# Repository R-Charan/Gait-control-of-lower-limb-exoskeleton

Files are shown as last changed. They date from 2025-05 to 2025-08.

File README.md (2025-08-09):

# Lower Limb Exoskeleton with Gait Control System

## 🦾 Project Overview

This project presents the design and development of an **underactuated lower limb exoskeleton** capable of augmenting human strength by **400%** while maintaining natural gait patterns. Unlike traditional 6+ DOF systems, our innovative 4-DOF approach (hip and knee joints only) provides effective power augmentation at reduced complexity and cost.

### Key Achievements
- **400% strength augmentation** validated through EMG testing
- **5x peak strength amplification** capability
- **Real-time gait pattern tracking** and control
- **Novel underactuated approach** with multi-point ground contact
- **Custom control architecture** with motion disturbance rejection

---

## Project Objectives

1. **Motor Control**: Configure torque and position controllers for BLDC motors
2. **Gait Analysis**: Analyze differences in gait patterns with/without load and exoskeleton
3. **Controller Development**: Implement PD + Bang-Bang controller for desired gait pattern tracing
4. **Strength Validation**: Test controller efficacy in augmenting user strength through force analysis
5. **EMG Validation**: Quantify strength amplification using electromyography data

---

## Technical Architecture

### Hardware Components
- **Motors**: BLDC motors with torque/position control
- **Sensors**: Inertial Measurement Unit (IMU) for feedback
- **Control**: Custom microcontroller unit with motor drivers
- **Power**: Battery system for portable operation
- **Mechanical**: 4-DOF exoskeleton frame (hip and knee joints)

### Control System
```
Setpoint Generation → PD Controller → Bang-Bang Control → Motor Actuation
        ↑                                                        ↓
    Gait Pattern                                            IMU Feedback
```

### Software Architecture
- **Angle Update Module**: Real-time joint angle monitoring
- **Controller Module**: PD control with dynamic motion disturbance rejection
- **Actuation Module**: Speed-to-duty cycle mapping with threshold-based system control

---

##  Methodology

### 1. Hardware Setup & Integration
- Motor and driver configuration
- IMU calibration and mounting
- Battery and power management system
- Mechanical assembly and testing

### 2. Control Algorithm Development
- **Position Controller**: Single DOF motor position control
- **Gait Generation**: Algorithm for natural walking pattern synthesis
- **PD + Bang-Bang Controller**: Hybrid approach for robust tracking
- **Motion Compensation**: Dynamic disturbance rejection system

### 3. Validation & Testing
- **Single leg gait cycle testing**
- **Controller response analysis**
- **EMG data acquisition and analysis**
- **Strength augmentation quantification**

---

## Results

### Control Performance
- Successfully achieved repeating gait cycles
- Stable position control with measured time-domain response
- Effective motion disturbance rejection

### Strength Augmentation Validation
**EMG Analysis Results:**
- **Without Support**: Max amplitude ~0.8mV (burst activity)
- **With Exoskeleton**: Max amplitude ~4mV with continuous 1mV baseline
- **Conclusion**: 5x peak strength amplification, 400% overall augmentation

### Key Findings
1. **Multi-core Processing**: Parallel control for multiple DOF systems recommended
2. **Speed vs. Torque Control**: Current-based control approaches preferred for robustness
3. **Impedance Control**: Direct torque input more effective than speed-based control
4. **Validation Success**: Low-cost prototype successfully augments user strength

---

## System Architecture

### Kinematic Model
```
Hip Joint (θh, ωh) → Thigh Link (lt) → Knee Joint (θk, ωk) → Shank Link (ls) → Ankle
```

### Compensation Algorithm
For undisturbed shank angular position during thigh motion:
```
θ̇k = -ωh (compensation velocity for knee actuator)
```

### Control Equations
- **Position Control**: PD controller with setpoint lookup table
- **Motion Compensation**: Dynamic adjustment based on hip joint velocity
- **Actuation Mapping**: Speed-to-duty cycle conversion with threshold control

---

## Implementation Details

### PCB Design
- Custom circuit board for motor control integration
- IMU interface and data acquisition
- Power management and battery monitoring

---

### Key Functions
- **Angle Update**: Real-time joint angle monitoring via IMU
- **Setpoint Lookup**: Gait pattern reference generation
- **Error Calculation**: Position error computation for control
- **Speed Mapping**: Controller output to motor speed conversion
- **Threshold Control**: Safety and performance optimization

---

## Performance Metrics

| Metric | Value | Validation Method |
|---|---|---|
| Strength Augmentation | 400% | EMG Analysis |
| Peak Strength Amplification | 5x | EMG Peak Comparison |
| Control DOF | 4 (Hip + Knee) | System Design |
| Response Time | Real-time | Controller Testing |
| Ground Contact | Multi-point | Mechanical Design |

---

## Future Work

### Immediate Improvements
- **Multi-core Implementation**: Parallel processing for enhanced performance
- **Torque-based Control**: Direct current control for improved robustness
- **Impedance Control**: Enhanced human-robot interaction
- **Response Tuning**: Further PD parameter optimization

### Advanced Features
- **Adaptive Control**: Machine learning-based gait adaptation
- **Wireless Communication**: Remote monitoring and control
- **Energy Harvesting**: Self-sustaining power systems
- **Full-body Integration**: Extension to upper limb assistance

---

## Team

**Project Members:**
- Adithya Venkata Narayanan – 111120001
- R Charan Bhardhwaj – 111120109

**Project Guides:**
- Dr. N Siva Shanmugam (Internal Guide)
- Dr. D Ezhilarasi (Co-Guide)

---

## Key References

1. **Kinoshita, H. (1985)**. Effects of different loads and carrying systems on selected biomechanical parameters describing walking gait. *Ergonomics, 28(9), 1347–1362.*

2. **Al-Shuka, et al. (2019)**. Biomechanics, actuation, and multi-level control strategies of power-augmentation lower extremity exoskeletons: an overview. *International Journal of Dynamics and Control, 7(4), 1462–1488.*

3. **Grimmer, et al. (2020)**. Human Lower Limb Joint Biomechanics in Daily Life Activities: A Literature Based Requirement Analysis for Anthropomorphic Robot Design. *Frontiers in Robotics and AI, 7.*

---

## Project Impact

This research addresses a critical gap in exoskeleton technology by demonstrating that **underactuated systems** can provide effective power augmentation comparable to traditional higher-DOF systems. The work contributes to:

- **Cost-effective Design**: Reduced complexity while maintaining performance
- **Novel Control Approach**: PD + Bang-Bang hybrid controller
- **Validated Performance**: Quantified strength augmentation through EMG
- **Real-world Application**: Practical solution for load-bearing augmentation

---

## License

This project is part of academic research conducted at National Institute of Technology, Tiruchirapalli. Please cite appropriately if using this work for research purposes.

*This project represents a significant step forward in making exoskeleton technology more accessible and practical for real-world applications.*

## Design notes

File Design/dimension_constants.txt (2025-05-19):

"thigh_width"= 3cm

"thigh_thickeness"= 1cm

"shin_thickness"= 0.6cm

"shin_width"= 5cm

"D1@Sketch7"="thigh_width"+2cm

"link_length" = 8.5cm

"D2@Sketch7"="link_length"

"D1@Boss-Extrude5"="thigh_thickeness"

"D2@Sketch8"="thigh_width"-2mm

"bolt head"= 4.2mm'With clearance

"D3@Sketch16"="bolt head"

"D4@Sketch16"="bolt head"

"D5@Sketch16"="bolt head"

"D6@Sketch16"="bolt head"

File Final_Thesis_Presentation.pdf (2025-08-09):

# Gait Control of Lower Body Exoskeleton

## B. Tech Final Year Project Review

Project Members

Adithya Venkata Narayanan – 111120001 R Charan Bhardhwaj – 111120109

Project Guides

Dr. N Siva Shanmugam (Internal Guide) Dr. D Ezhilarasi (Co – Guide)

# Introduction

What is Gait?
Gait refers to the movement pattern of the limbs during locomotion, commonly associated with walking. It involves a coordinated sequence of movements of the legs and arms to propel the body forward.
What happens to gait under load?
Adding weights alters the biomechanics of gait by increasing the load on muscles and joints. It may lead to changes in stride length, step frequency, and overall stability as the body adapts to the added load.

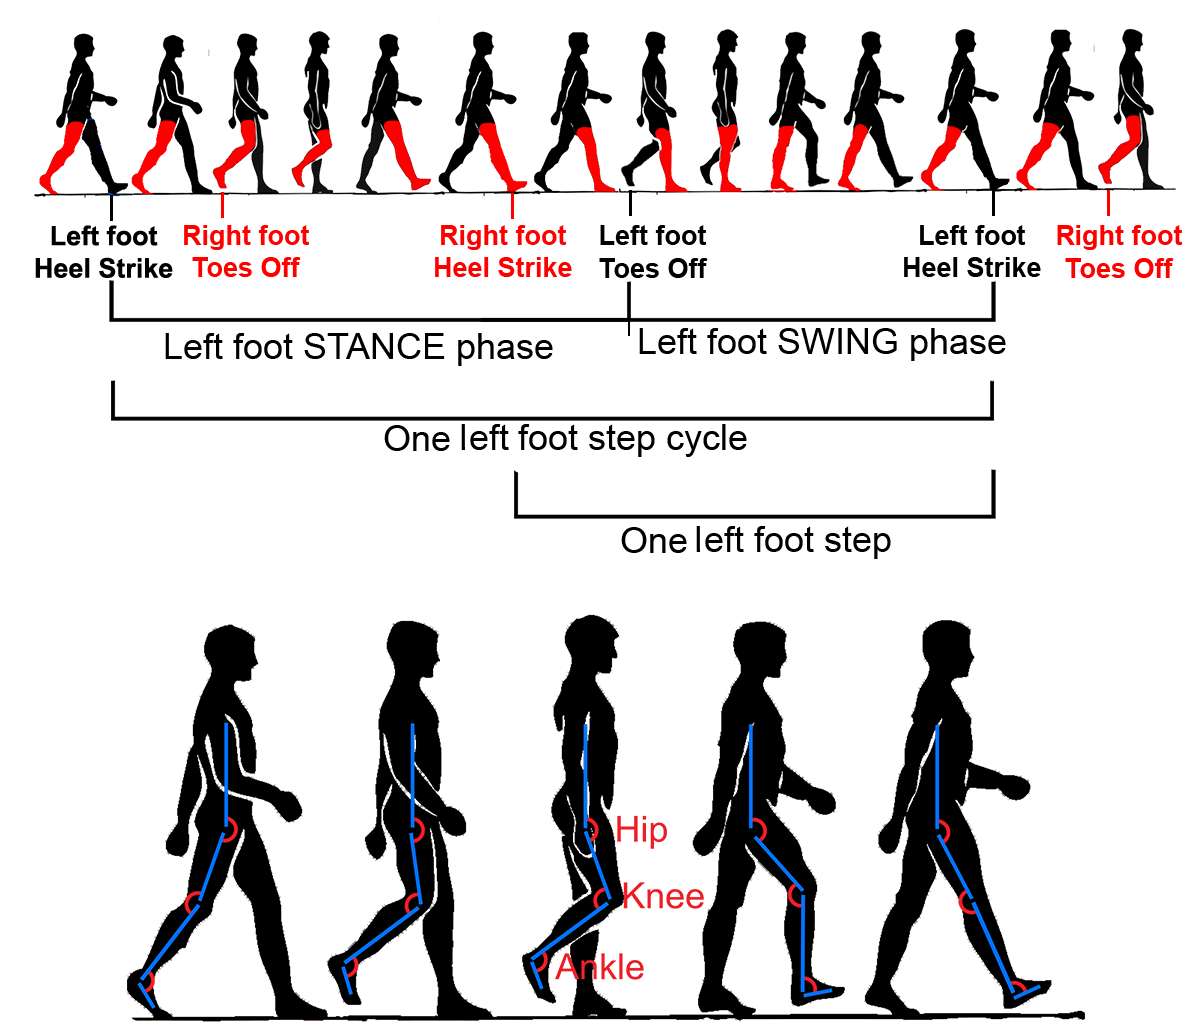
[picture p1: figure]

Image Source: Georgiou, T., et.al (2020)

# Introduction (Continued)

What are Exoskeletons?
Exoskeletons are wearable robotic devices (over specific regions or overall, of the body) designed to enhance physical performance. They augment power by providing mechanical assistance to muscles, reducing fatigue, and increasing endurance.
How do exoskeletons help?
Exoskeletons distribute weight more evenly across the body, changing the load path and thus reducing the strain on muscles and joints during weight-bearing activities. By supporting the load, exoskeletons enable individuals to carry heavier objects with less effort, improving overall mobility and productivity.

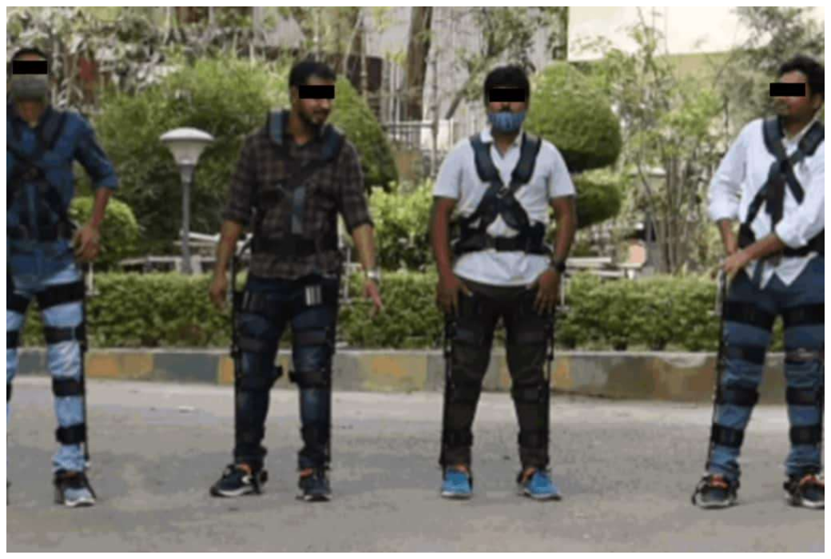
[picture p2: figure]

Image Source: DRDO developing exoskeleton for the Indian soldiers posted in high altitudes, Financial Express

# Literature Review

S.No | Source | Title | Inference
1 | Kinoshita, H. (1985). Ergonomics, 28(9), 1347–1362. | Effects of different loads and carrying systems on selected biomechanical parameters describing walking gait | Significant change of body posture and gait pattern observed when lifting heavy weights , indicating that the risk of encountering stress-related injuries is considerably greater as the load increased in magnitude.
2 | Al-Shuka, et. al (2019).International Journal of Dynamics and Control, 7(4), 1462– 1488. | Biomechanics, actuation, and multi-level control strategies of power-augmentation lower extremity exoskeletons: an overview | Factors such as interaction force wrench for control purpose, among others required for force augmentation to be considered for design of a control strategy for power augmentation in exoskeletons were discussed.
3 | Grimmer, et. al. (2020). Frontiers in Robotics and AI, 7. | Human Lower Limb Joint Biomechanics in Daily Life Activities: A Literature Based Requirement Analysis for Anthropomorphic Robot Design. | A study of the range of motion and joint parameters (velocity, acceleration, torque, and power)exhibited by healthy subjects alongside a motion study of actions (such as walking, jogging, running, climbing, and sitting to standing) was presented.

# Literature Review

S.No | Source | Title | Inference
4 | Zoss, A, et. al. (2006). IEEE-ASME Transactions on Mechatronics, 11(2), 128–138. | Biomechanical Design of the Berkeley Lower Extremity Exoskeleton (BLEEX) | Introduces the 14 DOF (7 DOF per leg) lower extremity exoskeleton for power augmentation that anthropomorphic in design.
5 | Amiri, M. S, et. al. (2019). IEEE Access, 7, 167210–167220. | Initialized Model Reference Adaptive Control for Lower Limb Exoskeleton | A comparative study of IMRAC and non-IMRAC rule on a closed-loop PID controller detailing the mathematical expression of the control schemes' LLE structure, transfer function, and convergence rates

# Literature Gap

- Augmentative exoskeletons are not available in the market, and the research sector covers

### the entire leg with hip, knee, and ankle actuators (at least 6 DOF). The under-actuated

exoskeletons (4 DOF, hip, and knee) in literature are still in the research phase, with their

### dynamic models either being treated as ones with single-point contact at the foot between the unit and the ground or having no contact with the ground (model, ends at above the

ankle joint). • A gap exists in the literature where the exoskeleton is underactuated, having a complete

metallic sole unit in contact with the ground (multi-point contact). • The approach for designing controller for exoskeletons and its implementation is not

available in literature.

# Aim

### - Our work involves designing a controller for an underactuated Lower Limb Exoskeleton (4 DOF, only hip and knee joint control) that enhances the user's load-bearing capacity and

testing the unit's efficacy on a flat plane. Thus, the feasibility of an underactuated system to provide power augmentation like traditional higher DOF exoskeletal systems is determined. • We aim to work on an approach that strikes a balance between extensive modelling and

### model free PID approaches. Studying kinematics and dynamics to design compensators for

over/undershoots on top of a PID architecture.

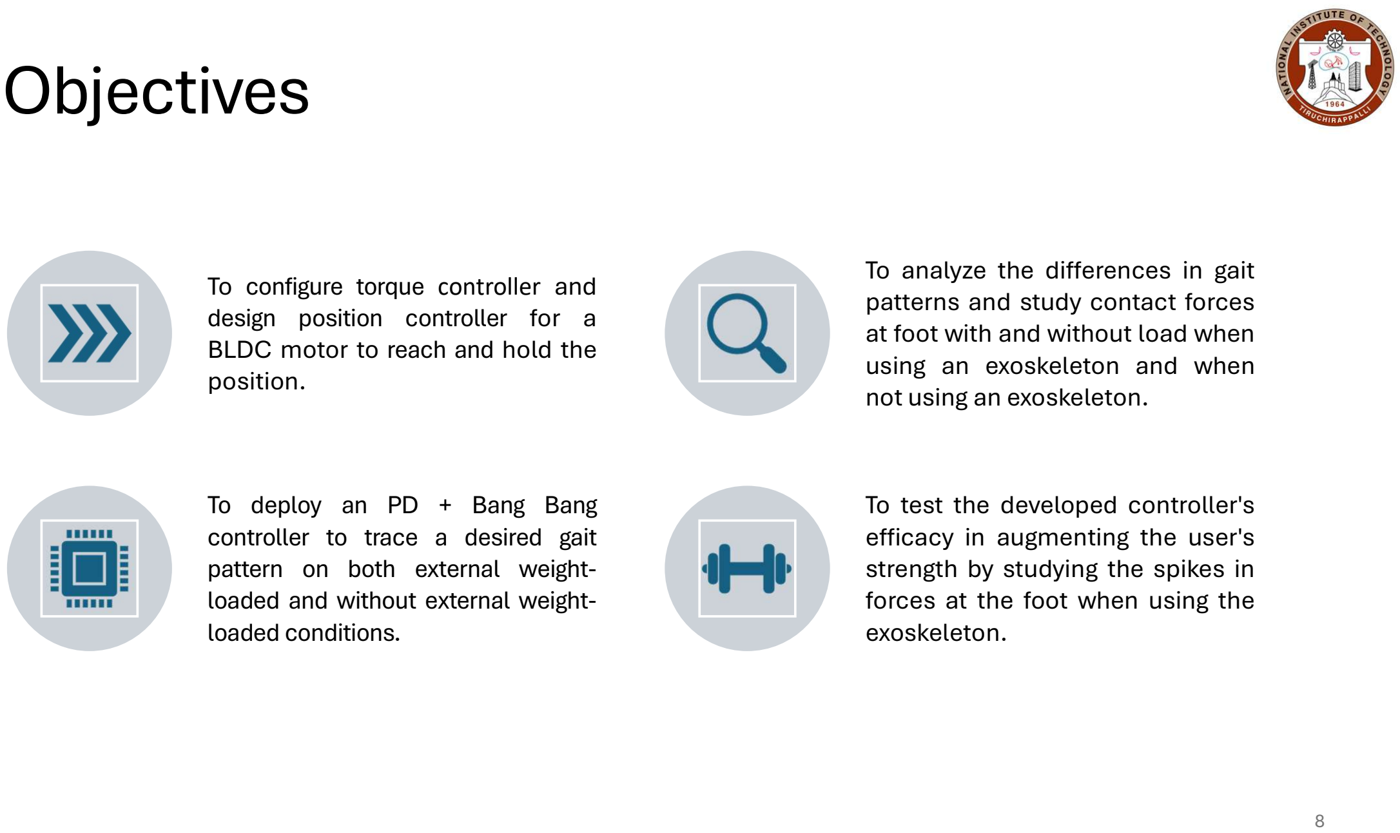
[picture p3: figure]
To configure torque controller and design position controller for a BLDC motor to reach and hold the position.; To analyze the differences in gait patterns and study contact forces at foot with and without load when using an exoskeleton and when not using an exoskeleton.; To deploy an PD + Bang Bang controller to trace a desired gait pattern on both external weight- loaded and without external weight- loaded conditions.; To test the developed controller's efficacy in augmenting the user's strength by studying the spikes in forces at the foot when using the exoskeleton.; Objectives

# Methodology

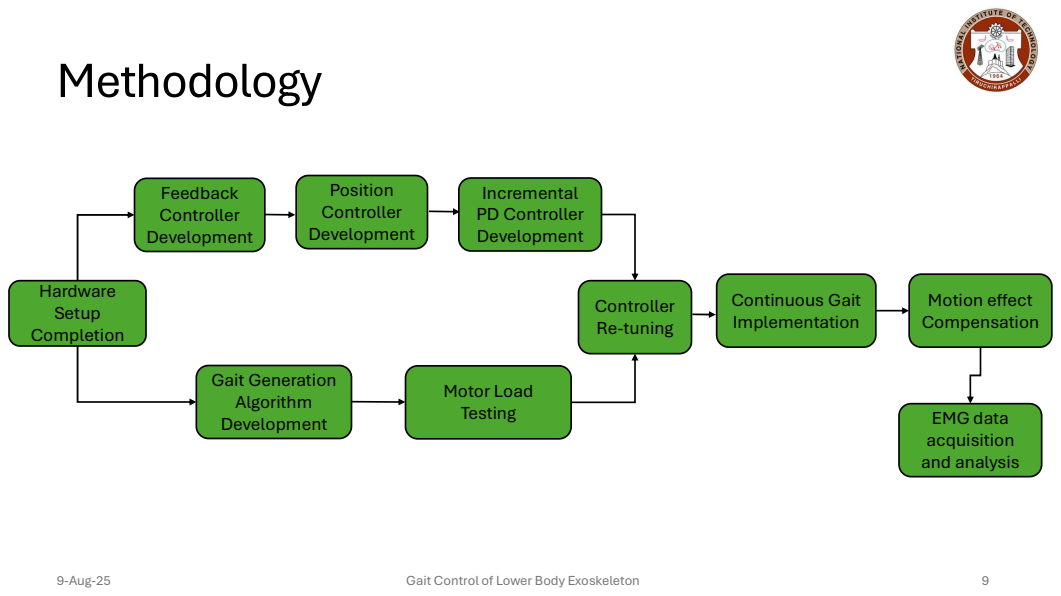
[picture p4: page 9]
9-Aug-25; Gait Control of Lower Body Exoskeleton; Hardware Setup Completion; Gait Generation Algorithm Development; Motor Load Testing; Position Controller Development; Incremental PD Controller Development; Controller Re-tuning; Continuous Gait Implementation; Motion effect Compensation; Feedback Controller Development; EMG data acquisition and analysis

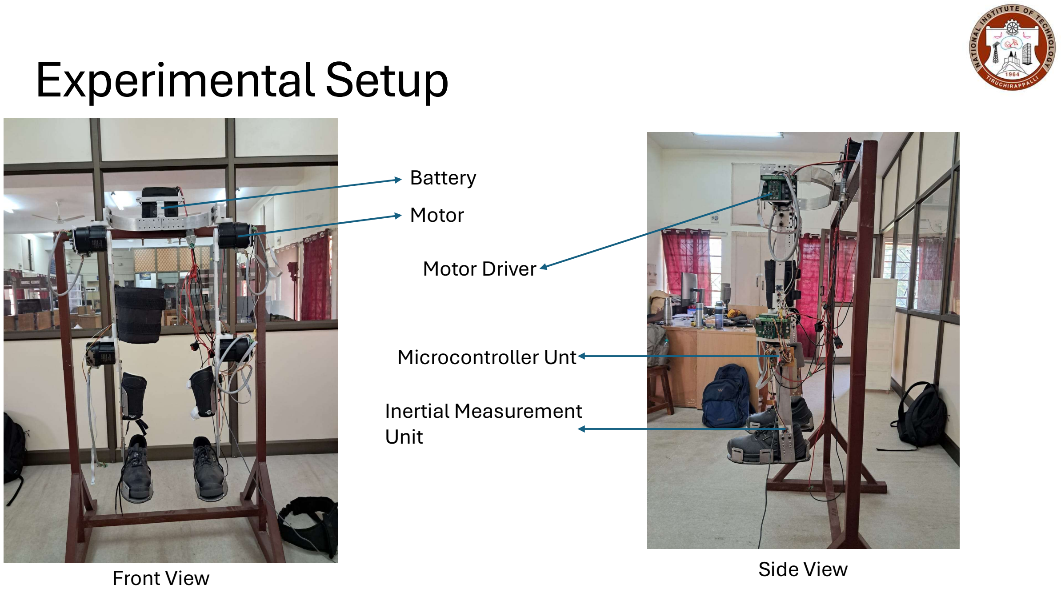
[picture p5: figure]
Experimental Setup; Motor; Battery; Front View; Motor Driver; Microcontroller Unt; Inertial Measurement Unit; Side View

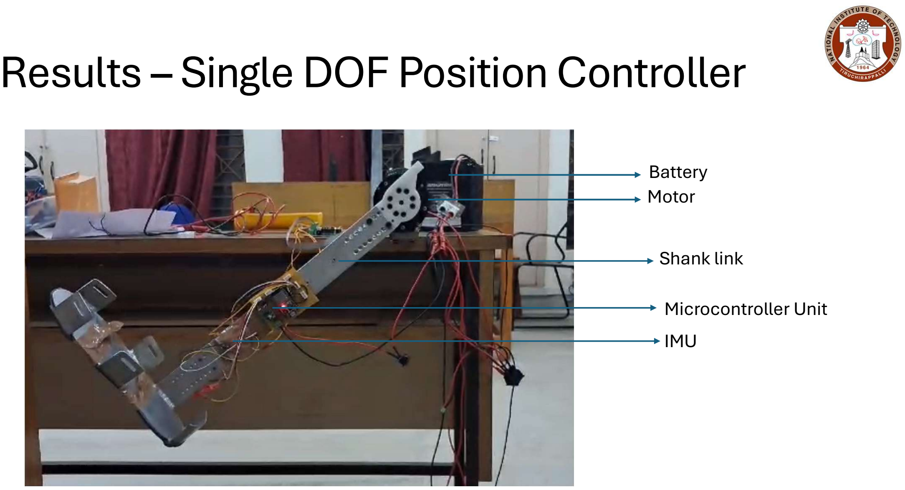
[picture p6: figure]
Battery Motor; Shank link; Microcontroller Unit IMU

# Results – Single DOF Position Controller

# Results – Gait Data Study and Visualization

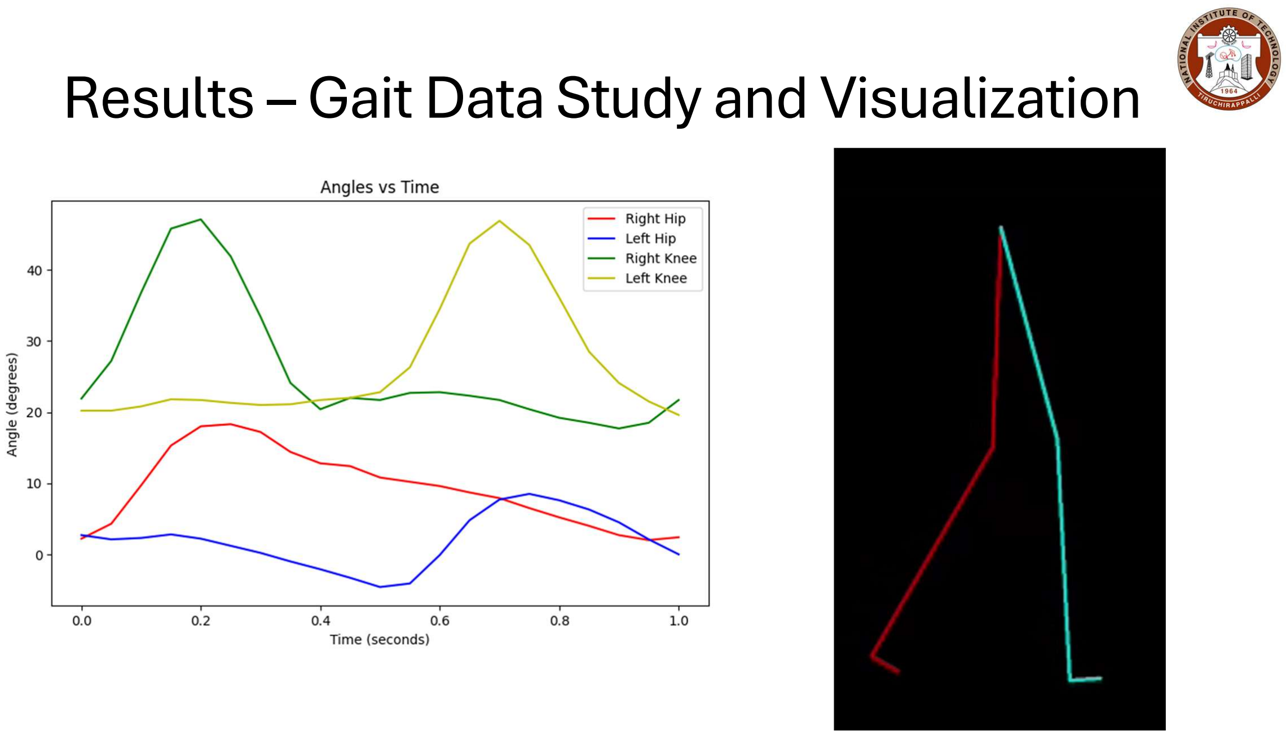
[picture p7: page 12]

# Controller Architecture

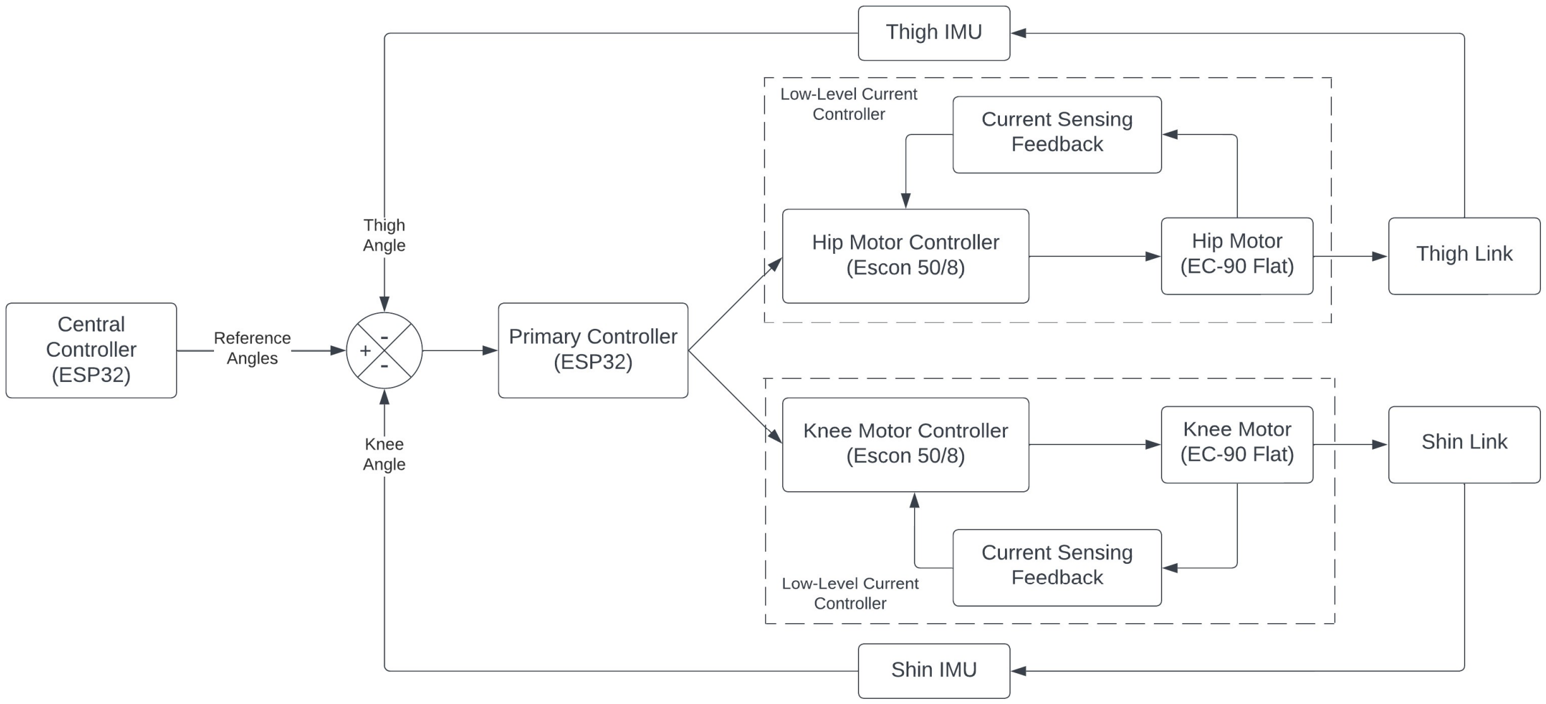
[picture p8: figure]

# Results - Single Leg Gait Cycle

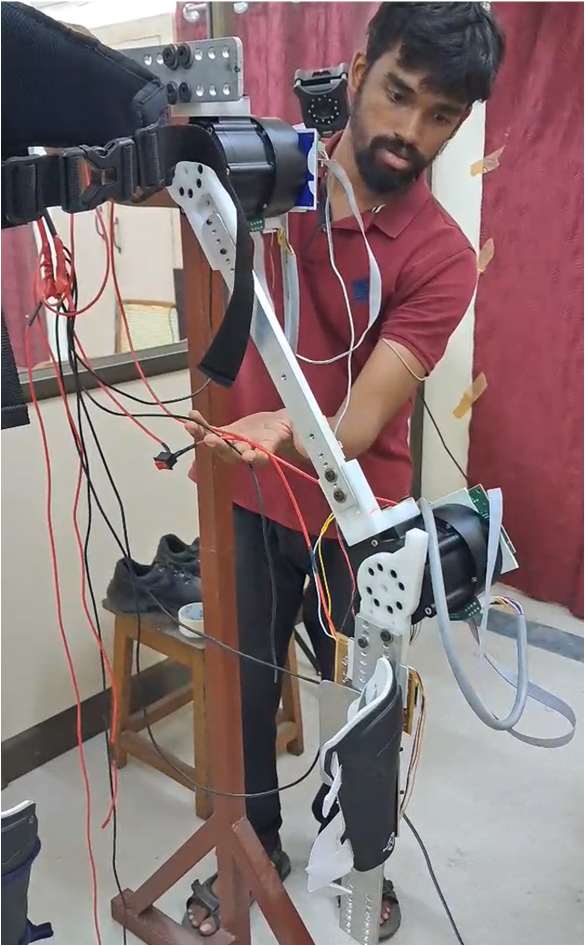
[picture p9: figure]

# Results – Controller Response

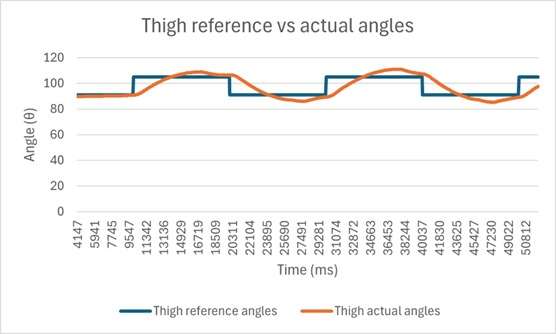
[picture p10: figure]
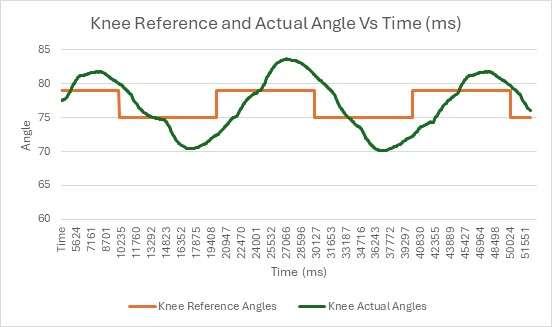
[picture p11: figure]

# Controller Response

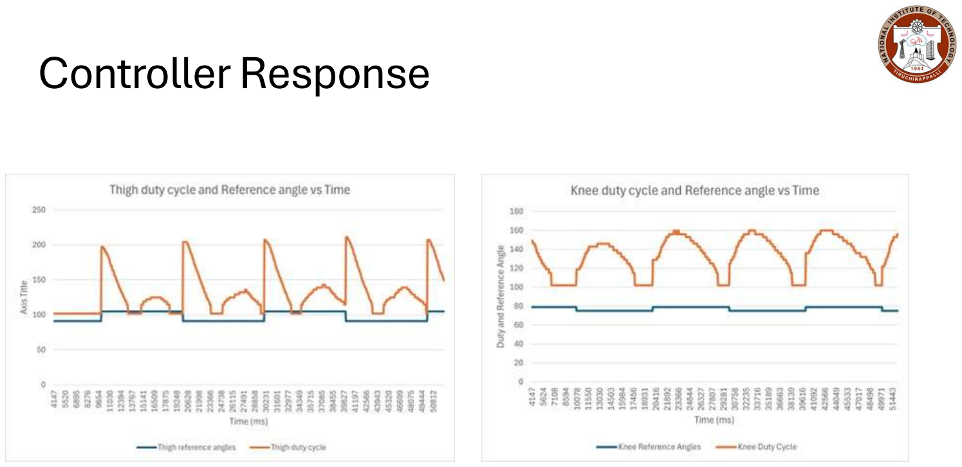
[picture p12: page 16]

# PCB Design

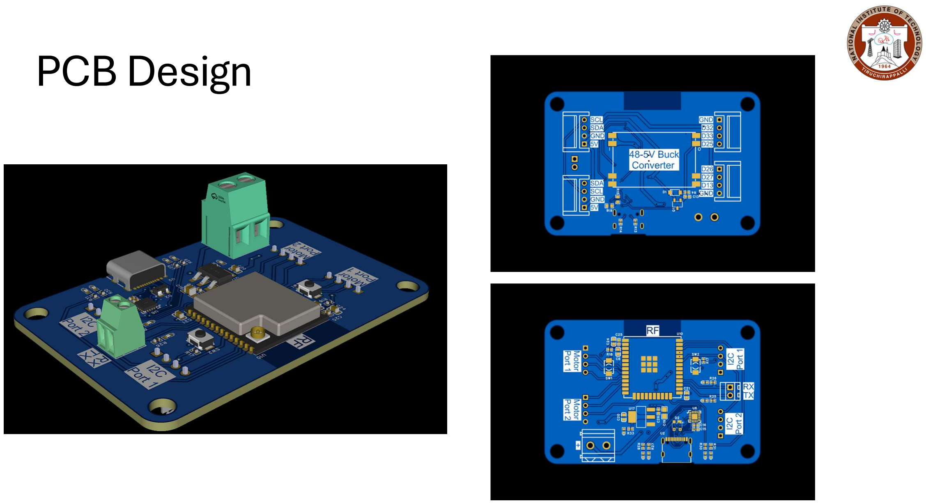
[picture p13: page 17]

# Code Base

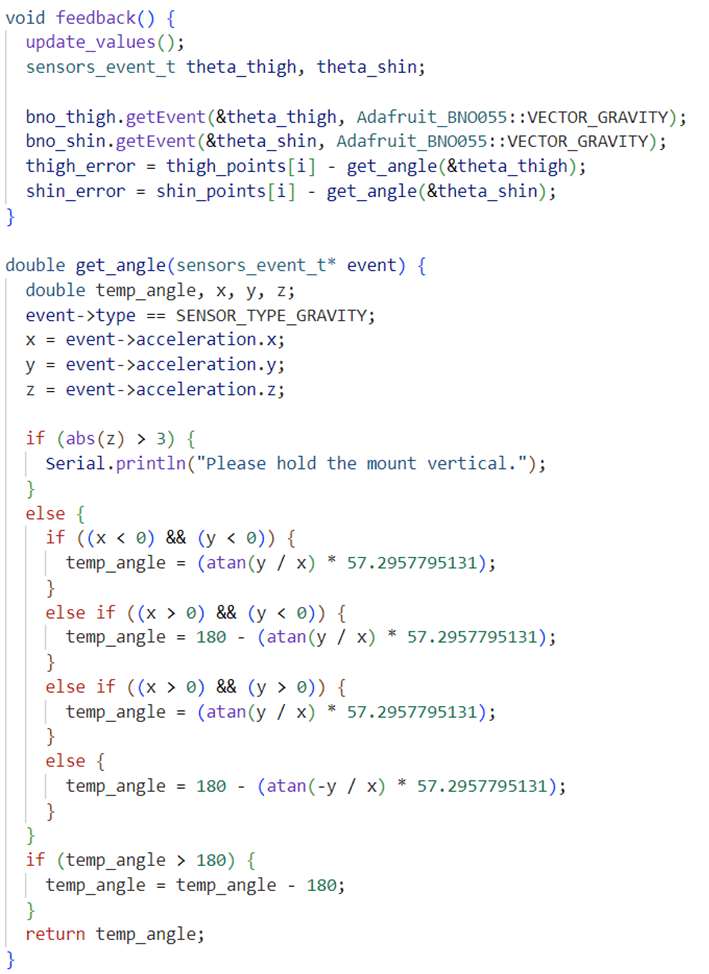
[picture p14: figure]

Angle Update

Feedback

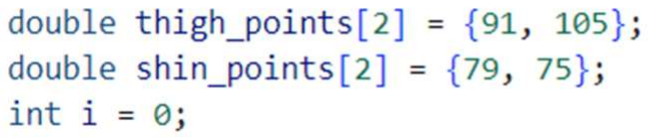
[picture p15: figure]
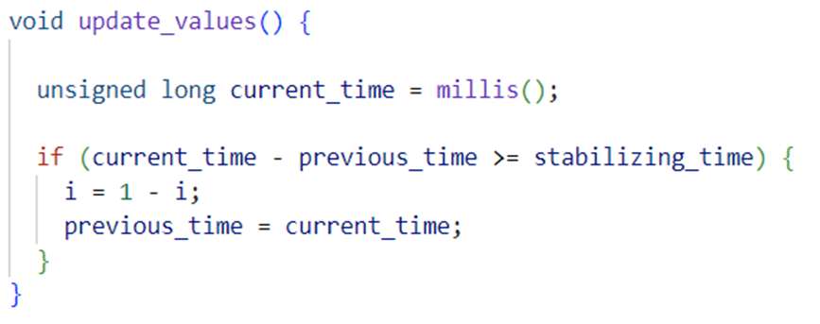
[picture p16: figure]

Setpoint look up table, and open loop timer based update function

# Code Base - Controller

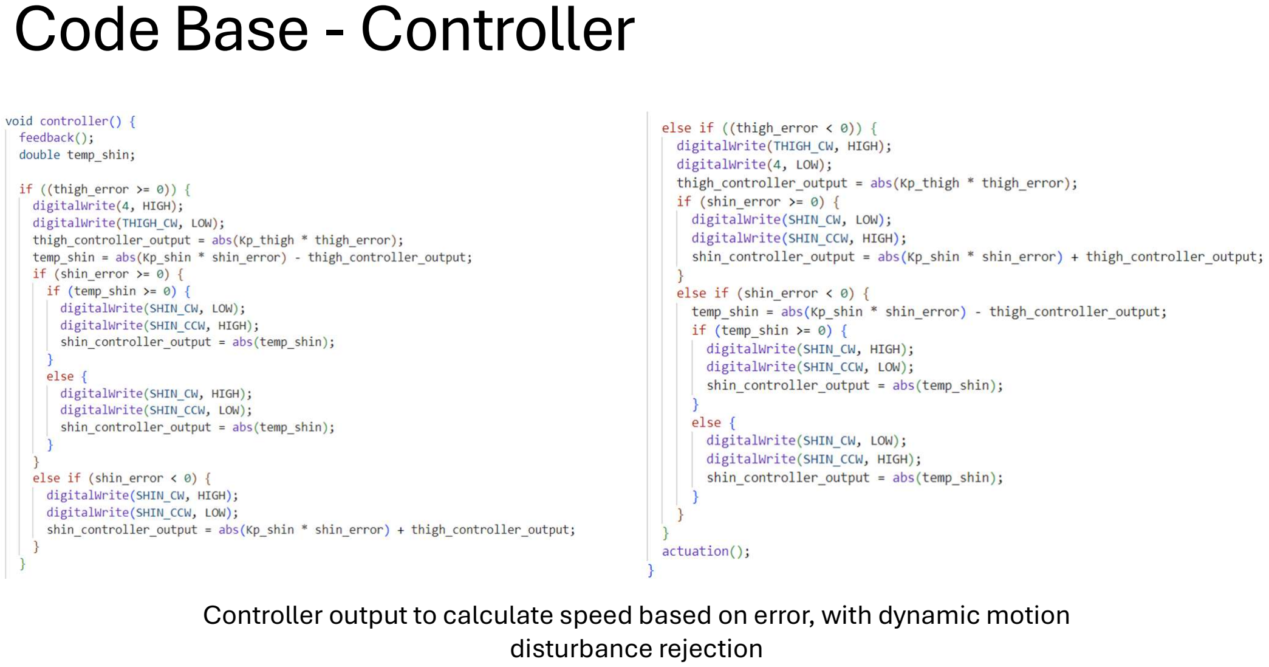
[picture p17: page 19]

Controller output to calculate speed based on error, with dynamic motion disturbance rejection

# Code Based - Actuation

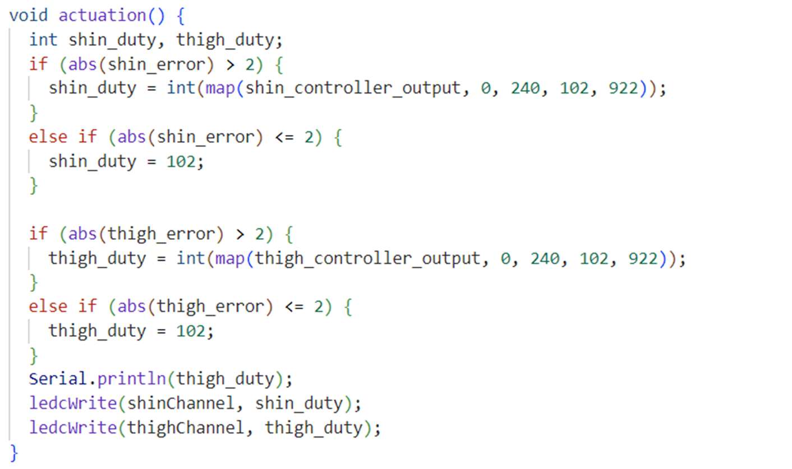
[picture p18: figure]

Map functions to convert speed into duty cycle, and threshold based system actuation

# Conclusion of the research

i. Repeating gait cycles and achieving poses is task that should be handled in parallel for multiple DOF systems. Microcontrollers with more than one core should be employed for the task of position control, with each core monitoring one motion.
ii. The time domain response of the system on a square wave setpoint pulse has been noted. Further response-based PD tuning of the controller is now possible, since require data was obtained.
iii. A speed-based control, although easier to deploy, is not the most robust solution to the position control task. This is due to the absence of an element of impedance control or a direct torque-based input. As such, it is advisable to work on current based control approaches.

iv. The exoskeleton was worn, and EMG data output on actuation was studied to quantify that the user strength was amplified by a factor of 5. Thus, the low-cost exoskeleton prototype can augment user strength.

# References

- Al-Shuka, Hayder & Rahman, Mohammad & Leonhardt, Steffen & Ciobanu, Ileana & Berteanu, Mihai. “Biomechanics, actuation, and multi-level control strategies of power-augmentation lower extremity exoskeletons: an overview.” International Journal of Dynamics and Control (2019): 1462-1488. • Barbareschi G, Richards R, Thornton M, Carlson T, Holloway C. “Statically vs dynamically balanced gait: Analysis of

a robotic exoskeleton compared with a human.” 37th Annual International Conference of the IEEE Engineering in Medicine and Biology Society. IEEE, 2015. 6728-6731. • Conor James Walsh, Ken Endo, Hugh Herr. “A Quasi-Passive Leg Exoskeleton For Load-Carrying Augmentation.”

International Jounral of Humanoid Robotics 8 March 2007: 487-506. • Dasari Karthik, C.B Kameswara Rao. “Identifying the significant factors affecting the masonry labour productivity.”

Internal Journal of Construction Management (2022): 464-472. • Durda, Frank. “Serial and UART Tutorial.” 2021. • ExRx. Body Segment Data. n.d. <https://exrx.net/Kinesiology/Segments>. • H. Kazerooni, J.-L. Racine, Lihua Huang, R. Steger. “On the Control of the Berkeley Lower Extremity Exoskeleton

(BLEEX).” Proceedings of the 2005 IEEE International Conference on Robotics and Automation. Berlin: IEEE, 2006. • Hao Lee, Peter Walker Ferguson and Jacob Rosen. “Lower Limb Exoskeleton Systems—Overview.” Wearable

Robotics (2019). • Kinoshita, Hiroshi. “Effects of different loads and carrying systems on selected biomechanical parameters

describing walking gait.” Ergonomics (1985): 1347-1362.

- M. Fontana, R. Vertechy, S. Marcheschi, F. Salsedo, M. Bergamasco. “The body extender: a full-body exoskeleton for the transport and handling of heavy loads.” Robotics and Automation 2014: 34-44. • M. Vukobratovic, B. Borovac and V. Potkonjak. “Towards a unified understanding of basic notions and terms in

humanoid.” Robotica (2006): 87-101. • Makinson, G. E. C. S. M. H. P. Operation and B. Research and Development Prototype for Machine Augmentation

of Human Strength and Endurance: Hardiman I Project. The Company, 1971. • Martin Grimmer, Ahmed A. Elshamanhory, Philip Beckerle. “Human Lower Limb Joint Biomechanics in Daily Life

Activities: A Literature Based Requirement Analysis for Anthropomorphic Robot Design.” Humanoid Robotics (2020). • Michael R Tucker, Jeremy Olivier, Anna Pagel, Hannes Bleuler, Mohamed Bouri, Olivier Lambercy, José del R

Millán, Robert Riener, Heike Vallery & Roger Gassert. “Control strategies for active lower extremity prosthetics and orthotics: a review.” Journal of NeuroEngineering and Rehabilitation (2015). • Neumann, D.A. Kinesiology of the Musculoskeletal System: Foundations for Physical Rehabilition. Mosby, 2009. • Norazam Aliman, Rizauddin Ramli, Sallehuddin Mohamed Haris. “Design and development of lower limb

exoskeletons: A survey.” Robotics and Autonomous Systems (2017): 102-116. • Robert V. Schulte, Erik C. Prinsen, Leendert Schaake, Robert P. G. Paassen, Marijke Zondag, Eline S. van

Staveren, Mannes Poel & Jaap H. Buurke. “Database of lower limb kinematics and electromyography during gait-related activities in able-bodied subjects.” Scientific Data (2023). • Sai K. Banala, Sunil K. Agrawal, Abbas Fattah, Vijaya Krishnamoorthy, Wei-Li Hsu, John Scholz, Katherine

Rudolph. “Gravity-Balancing Leg Orthosis and Its Performance Evaluation.” IEEE Transactions on Robotics. IEEE, 2006. 1228 - 1239. • Sul, Seog-Joo Kang and Seung-Ki. “Direct Torque Control of Brushless DC Motor with Nonideal Trapezoidal Back

EMF.” IEEE Transactions on Power Electronics 6 November 1995.

- Vikash Kumar, Yogesh V. Hote, Shivam Jain. “Review of Exoskeleton : History, Design and Control.” 3rd International Conference on Recent Developments in Control, Automation & Power Engineering (RDCAPE). IEEE, 2019. 677-682. • Walter Pirker, Regina Katzenschlager. “Gait disorders in adults and the elderly.” Wien Klin Wochenschr (2016). • Yagn, N. US: Patent 420179. 1890. • Zhiguo Feng, Jinwu Qian, Yanan Zhang, Linyong Shen, Zhen Zhang, Qiyuan Wang. “Biomechanical design of the

powered gait orthosis.” IEEE International Conference on Robotics and Biomimetics (ROBIO). Sanya: IEEE, 2007. 1698-1702.

# Appendix – System Modelling for Controller Design

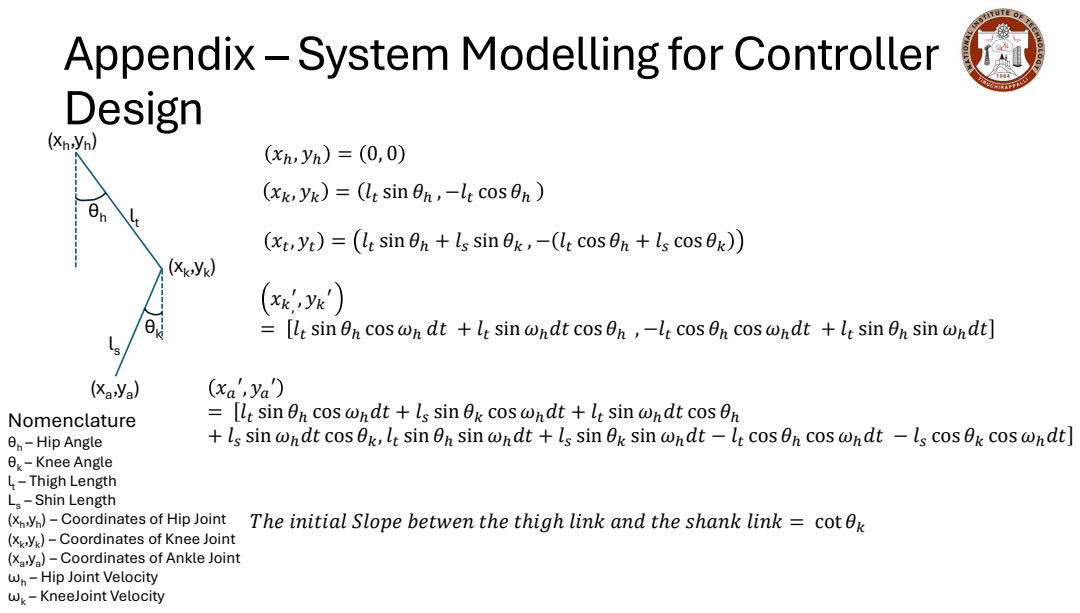
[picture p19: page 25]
Nomenclature θh; – Hip Angle; – Knee Angle lt – Thigh Length Ls (xh (xk (xa ωh ωk; sin θ , −l; cos θ; sin θ + l; sin θ , − l; cos θ + l; sin θ cos ωdt + l

sin θ cos ω dt + l

sin ωdt cos θ , −l

cos θ cos ωdt + l

sin θ sin ωdt

sin θ cos ωdt + l
sin θ sin ωdt + l

sin ωdt cos θ
sin θ sin ωdt − l

cos θ cos ωdt]

sin ωdt cos θ, l

cos θ cos ωdt − l

– Shin Length
– Hip Joint Velocity
– KneeJoint Velocity

) – Coordinates of Hip Joint
) – Coordinates of Knee Joint
) – Coordinates of Ankle Joint

Tℎe initial Slope betwen tℎe tℎigℎ link and tℎe sℎank link = cot θ

# Continued

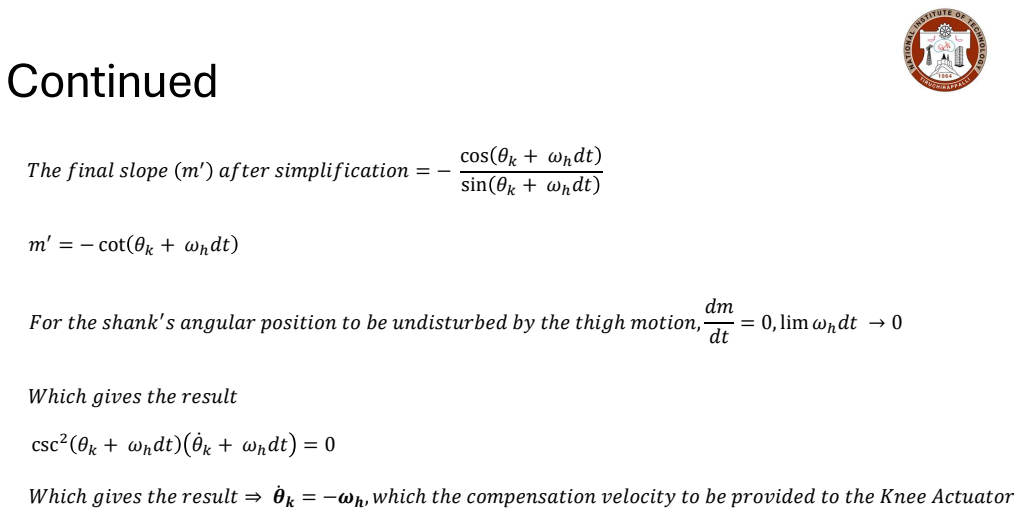
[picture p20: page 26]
after simplification = −; cos θ + ωdt sin θ + ωdt; m = − cot θ + ωdt; csc

Tℎe final slope m

dt = 0, lim ωdt → 0

For tℎe sℎanks angular position to be undisturbed by tℎe tℎigℎ motion,

Wℎicℎ gives tℎe result

Wℎicℎ gives tℎe result ⇒ θ̇k = −ωh, wℎicℎ tℎe compensation velocity to be provided to tℎe Knee Actuator

# Appendix: Validation of exoskeleton strength augmentation

### An experiment was conducted to quantify the strength and amplification capability of the

exoskeleton. As such, a test subject was made to wear the exoskeleton and lift one leg with

### and without the support of the exoskeleton. EMG data from the quadriceps muscle group was

taken as a measure of quantification of the muscle activity (the motion of the muscle, caused

### neural or from external support - by the exoskeleton) Experiment Design (based on Seniam standards): 1.Target Muscle Group: The Rectus Femoris muscle is one of the dominant supporting

muscles that lift the leg.

### 2.Sensors Used: An EMG Sensor with 3M electrodes was used, with a data sampling

frequency of 2000Hz.

### 3.Electrode Placement: Three electrodes were placed on the target muscle, and one was placed close to the ankle joint bone as a reference. The inter-electrode separation is 20mm between the two electrodes on the muscle group. The direction of placement is in

the direction of the muscle fibers.

# Experiment Results

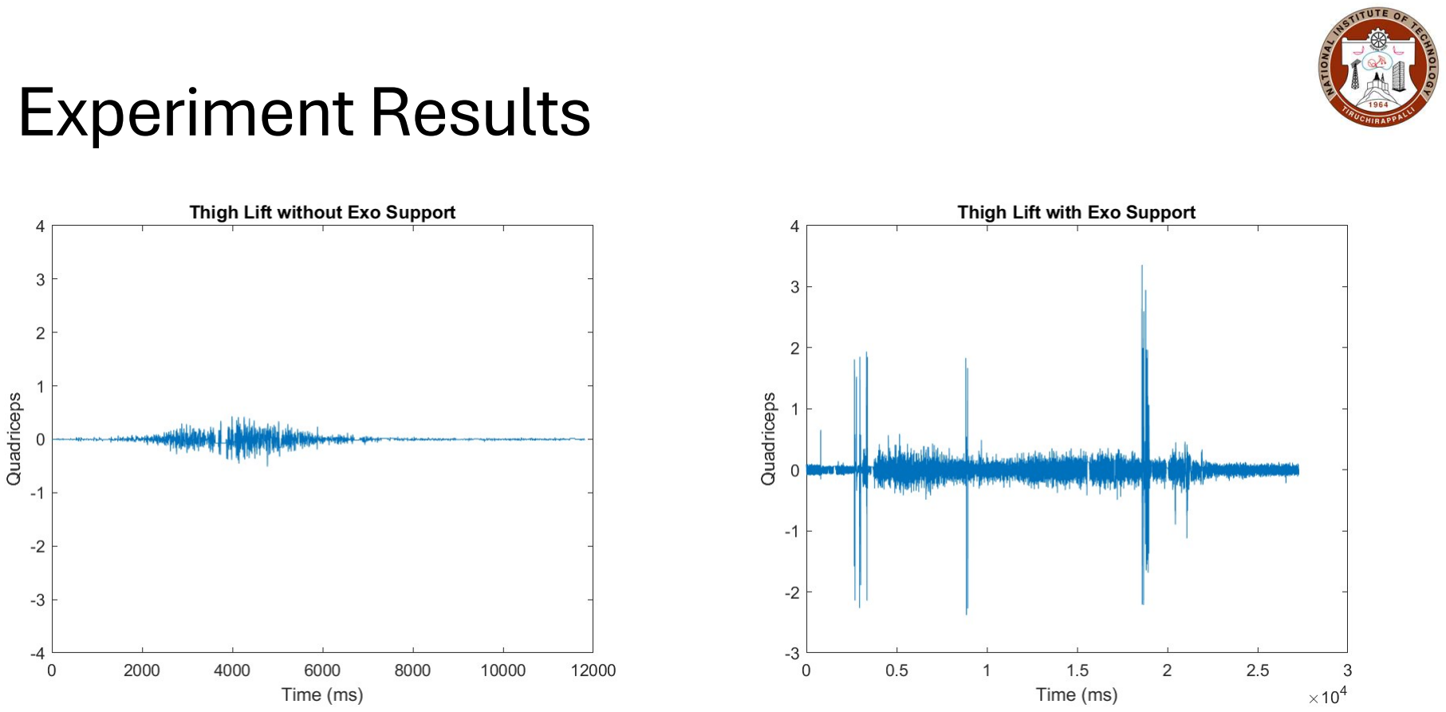
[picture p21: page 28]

# Inference:

The above EMG plots show the difference in muscle activity when the subject has no support in lifting and
when the exoskeleton is functional. • Case-1: | Without | support

The EMG data shows a maximum spike with an amplitude of approximately 0.8mV, and the action on the muscle is concise. The phase during which the muscle was made to do work is short—a burst
activity rather than a continuous activity. The rest of the plot shows close to no activity on the muscle. • Case-2: | With | exoskeleton | support

The EMG data shows multiple maximum spikes with an amplitude of approximately 4mV, with the rest of the plot showing muscle activity close to 1mV. The continuous activity is consistent throughout the entire plot, with higher activity being in a burst form.

# Conclusion:

From EMG data inferences, it can be concluded that the maximum strength exerted with support is five times that of without support. Moreover, the maximum strength with no support is the nominal strength with support. Thus, it can be concluded that the exoskeleton augments user peak strength by a margin of 400%, the nominal strength by a higher margin for higher durations.

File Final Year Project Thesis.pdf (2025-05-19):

## Gait Control of a Lower Limb Exoskeleton for Strength Augmentative Applications

### A thesis submitted in partial fulfilment of the requirements for

### the award of the degree of

B. Tech

in

Mechanical Engineering

By

ADITHYA VENKATA NARAYANAN (111120001)

R CHARAN BHARDHWAJ (111120109)

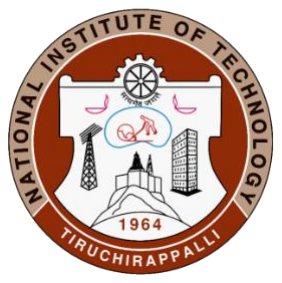
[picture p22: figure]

## DEPARTMENT OF MECHANICAL ENGINEERING

## NATIONAL INSTITUTE OF TECHNOLOGY

## TIRUCHIRAPPALLI – 620015

## May 2024

ii

Bonafide Certificate

This is to certify that the project titled “Gait Control of a Lower Limb

Exoskeleton for Strength Augmentative Applications” is a bonafide

record of the work done by

Adithya Venkata Narayanan (111120001)

R Charan Bhardhwaj (111120109)

in partial fulfilment of the requirements for the award of the degree of BACHELOR

OF TECHNOLOGY in MECHANICAL ENGINEERING at the

NATIONAL | INSTITUTE | OF | TECHNOLOGY,

TIRUCHIRAPPALLI, during the year 2023-2024.

Project Viva-voce held on: ____________________________________

Dr. N Siva Shanmugam

Project Guide

Dr. D Ezhilarasi

Project Co-Guide

Dr. K Pannirselvam

Head of the Department

Internal Examiner | External Examiner

iii

ABSTRACT

Lower body exoskeletons have emerged as promising tools for augmenting human

strength and mobility, offering significant potential for enhancing physical performance

and assisting individuals with mobility impairments. The research arena of lower-limb

exoskeletons focuses mainly on 12 DOF (Degrees of Freedom) models, and the market

prices of these models are unaffordable since a significant chunk of the cost are

attributed to the actuators.

The physical labour force exerts themselves to the maximum capabilities to carry heavy

weights in work site This can lead to workers injuring themselves in the long run.

Strength augmenting exoskeletons can be the solution to this problem, if made more

affordable. This thesis aims to investigate and analyse the capabilities of an 8 DOF (a

reduced DOF) lower limb exoskeleton to augment the strength of the user in performing

lifting activities.

To analyse the capabilities of the exoskeleton in augmenting user strength, the human

gait cycle was executed by making the setup autonomous. Maxon motors were

configured and tuned as per requirement as the motor drivers for Maxon motors can

execute a low-level current and speed control. Once the motors were configured and the

test bed setup was complete, the angular orientation was collected as the feedback using

an inertial measurement unit (IMU) which was used to calculate the difference between

the error in angular position of the exoskeleton’s links. A proportional controller was

used to compute the angular velocity input, to be fed to the motor controller, and thus

actuating the motor to reach the set point. A reference gait, which is the set of thigh and

shin angles to be traced was taken and fed to the microcontroller, providing necessary

PWM signals to make the links trace the desired gait trajectory.

Keywords: Lower Limb Exoskeleton, Gait, Walking Trajectory, Speed Control, Motor

Control, Hybrid Control Architecture.

iv

ACKNOWLEDGEMENTS

We would like to extend our sincere gratitude to Dr. G. Aghila, Director of National

Institute of Technology, Tiruchirappalli, for the invaluable cooperation extended to us,

which enabled the successful completion of our project.

We are deeply obliged to Dr. K. Pannirselvam, the Head of the Department of

Mechanical Engineering, for his unwavering support and encouragement. We are also

grateful to the esteemed members of the evaluation committee, Dr. S Suresh, Dr. N.

Siva Shanmugam, Dr. Bishweshwar Babu, and Dr. Raghu Ram Desu, for their valuable

advice, which significantly contributed to the refinement of our project. We would like

to sincerely thank the department of mechanical engineering for facilitating and

allowing us to pioneer and work on this thesis.

We owe a profound debt of gratitude to our guide, Dr. N Siva Shanmugam, for his

understanding, exceptional guidance and constant encouragement while facing highs

and lows throughout the duration of our research work. His expertise played a vital role

in our research journey, expanding our horizons and we are truly privileged to have had

the opportunity to work under his supervision.

We would also like to express our heartfelt gratitude to Dr. D Ezhilarasi (Co-guide), for

her continuous support. Her expertise and inspiration played an important role in our

journey, and we are truly blessed to have worked under her supervision as our co-guide.

Finally, we would like to acknowledge and thank our parents, relatives, and friends for

their unwavering love, emotional support, and unwavering belief in our abilities, which

provided us with the strength to overcome challenges and achieve our goals.

v

TABLE OF CONTENTS

vi

Code for performing continuous motion on a two degree of freedom system (one

vii

LIST OF TABLES

S. No | Table | Pg. No
1 | Table 4.1: Comparison of Pneumatic/Hydraulic actuators vs Motors | 24
2 | Table 5.1: System Behaviour w.r.t time | 42

viii

LIST OF FIGURES

S. No | Figure | Pg. No
1 | Fig 1.1: N. Yagn's Exoskeleton design | 11
2 | Fig 1.2: Hardiman 1 Full Body Exoskeleton | 11
3 | Fig 1.3: BLEEX | 12
4 | Fig 3.1: Planes of Analysis | 17
5 | Fig 3.2: Phases of walking cycle | 19
6 | Fig 3.3: Configurations of UART Communication | 21
7 | Fig 3.4: I2C Line Configuration | 22
8 | Fig 5.1: Current Control Block Diagram | 31
9 | Fig 5.2: Speed Control Block Diagram | 32
10 | Fig 5.3: Shin link position control | 35
11 | Fig 5.4: Overall Control Architecture | 36
12 | Fig 5.5: 2 DOF single leg gait cycle | 38
13 | Fig 5.6: Single Gait cycle plot | 38
14 | Fig A.1: Maxon Controller connection diagram | 46
15 | Fig C.1: PCB Footprint | 49
16 | Fig C.2: PCB Schematic | 50

ix

ABBREVIATIONS

1. DOF – Degrees of Freedom
2. BLDC – Brushless DC Motor
3. PD – Proportional Derivative
4. DC – Direct Current
5. ESC – Electronic Speed Controller
6. MOSFET – Metal Oxide Semiconductor Field Effect Transistor
7. PWM – Pulse Width Modulation
8. EMF – Electromotive Force
9. UART – Universal Asynchronous Receiver Transmitter
10. I2C – Inter Integrated Communication
11. TX – Transmitter
12. RX – Receiver
13. SDA – Serial Data
14. SCL – Serial Clock
15. IMU – Inertial Measurement Unit
16. FSR – Force Sensitive Resistor
17. EMG – Electromyography
18. EEG – Electroencephalogram
19. FOS – Factor of Safety
20. AWG – American Wire Gauge

x

NOMENCLATURE

1. θ – Angular Position
2. ω – Angular Velocity
3. α – Angular Acceleration
4. τ - Torque
5. i - Current
6. V - Voltage
7. l - Length
8. m – Mass
9. F - Force
10. I – Polar Moment of Inertia
11. g – Gravity
12. KP – Proportional Gain
13. KD – Derivative Gain

CHAPTER 1

INTRODUCTION

### 1.1 Background

Human exoskeletons robots are wearable robots that are powered by means of

pneumatic, hydraulic and, motors and gearbox or cable-driven (electromechanical

actuators), for multiple purposes. These include exoskeletons for assistive applications,

for rehabilitation exercises and for strength augmentative applications.

### 1.1.1 Brief History of Exoskeletons

N. Yagn’s conceptual model of robotic skeleton lays the foundation for the research of

exoskeleton. He designed a lower extremity enhancement model that was shaped like a

bow operating in parallel to the legs of the user as depicted in the Fig 1.1. Later in 1965,

General Electric designed the first full body powered exoskeleton that had 30 DOF and

weighed 680 Kgs (Makinson, 1971). The design is shown in the Fig 1.2.

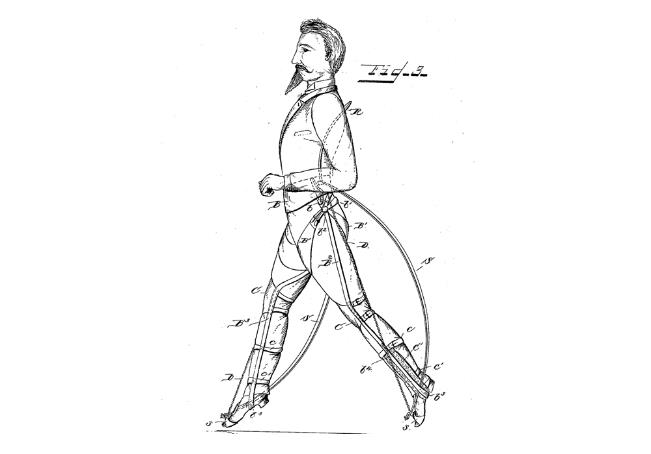
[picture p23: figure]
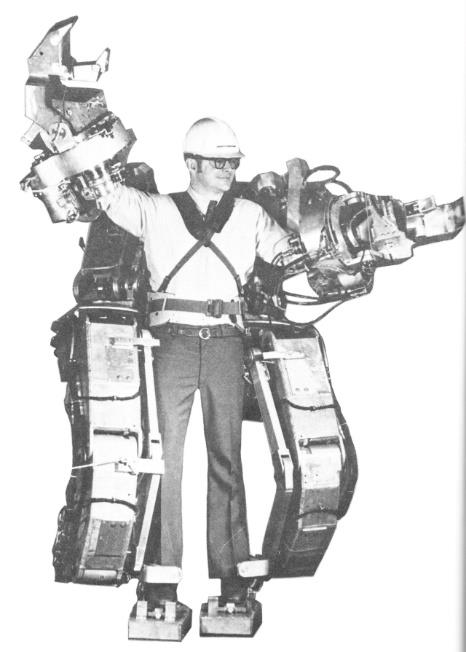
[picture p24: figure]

The Human Engineering and Robotics Laboratory (HERL), University of California,

Berkeley, designed and developed the first functional energetically autonomous load

Figure 1.1: N. Yagn's Exoskeleton design. (US Patent No. 420179, 1890)

Figure 1.2: Hardiman 1 Full Body Exoskeleton carrying human exoskeleton, the “Berkeley Lower Extremity Exoskeleton,” the

BLEEX in the year 2004. BLEEX was capable of walking at a pace of 1.3m/s under no

load condition and was able to walk at a pace of 0.9 m/s when a payload of up to 75 kg


was loaded (H. Kazerooni, 2006) (Vikash Kumar, 2019).

### 1.1.2 Types of Exoskeletons

Exoskeletons, based on their applications are primarily categorized into three types,

assistive, rehabilitation and augmentative exoskeletons.

Exoskeletons for assistive applications focuses on individuals who are unable to walk

normally due injuries that deal with the spinal cord, stroke or susceptible to effects of

aging. These exoskeletons are usually controlled by employing pre-defined trajectories

which are triggered by detecting the user’s intentions.

Exoskeletons are also used for the purpose of rehabilitation of patients who are

recovering from a surgery as well. Exoskeletons in these categories are designed to be

mounted to treadmill and their portability is not a priority when designing. Their control

primarily focuses on ensuring that the amount assistance provided decreases as time

passes if the patients using these rehabilitative robots develop more strength.

The third category of exoskeletons are designed to augment the strength and ability of

a healthy human. These types of exoskeletons are primarily targeted in the military

applications to allow the personnel to be able lift heavy objects such as weaponry or

Figure 1.3: BLEEX (H. Kazerooni, 2006)

other combatants in the event of an emergency. These types of exoskeletons should be

capable of complimenting the work done by the user. (Hao Lee, 2019).

In an augmentative exoskeleton, the assistance/strength augmentation can be directly

applied to the tasks. Such design of exoskeletons is not flexible and cannot be adapted

to different environments. On the other hand, is a class of augmentative exoskeletons

where strength assistance is applied on the user. This class of exoskeletons are weight

and power restricted as they cannot exceed weight limits of 150kg because it will reduce

the agility of the user completely (M. Fontana, 2014).

### 1.2 Motivation

A study done by Dasari Karthik et. al focusing on the masonry labour productivity in

building construction sites in India concluded that physical fatigue caused due to

extreme working conditions and lifting heavy weights accounts for 81% in Relative

Importance Index (RII). Another study conducted by D. A. Neumann proved that severe

injuries can be incurred through lifting heavy weights especially in regions such as the

lower back.

The common physical labour workforce is involved in lifting heavy weights daily that

can adversely affect their joint, muscle and their spinal health. Significant measures

must be taken to ensure that this workforce is less affected by adverse lifting conditions.

The motivation behind this thesis work is to provide cost-effective strength

augmentative lower limb exoskeleton that can be used in extreme situations to carry

loads that can affect human body.

### 1.3 Objectives

After a thorough analysis of the factors that have to be considered making the

exoskeleton cost-effective, the following objectives were shortlisted for this thesis.

The objectives are as follows:

a) To configure torque controller and design position controller for a BLDC motor

to reach and hold the position.

b) To deploy a PD + Bang Bang controller to trace a desired gait pattern on

both external weight-loaded and without external weight-loaded conditions.

c) To analyze the differences in gait patterns and study contact forces at foot with

and without load when using an exoskeleton and when not using an exoskeleton.

### 1.4 Chapter Overview

This section will provide an overview of the chapters. In chapter 2, an extensive

literature was conducted on topic of exoskeleton design considerations, control

strategies deployed in exoskeleton are presented. Chapter 3 will elucidate all the

important terminologies and the concepts needed to understand this thesis. Chapter 4

elaborates the experimental setup and chapter 5 is dedicated to the research

methodology undertaken to address the chosen statement. Chapter 6 provides the

conclusion and summarizes the result, and the future work.

CHAPTER 2

LITERATURE REVIEW

### 2.1 Impacts of lifting heavy weights

Kinoshita et. al investigated the change in the biomedical parameters of the human body

when the subjects walked under normal conditions and under load carrying conditions.

10 healthy male individuals were taken as test subjects and were made to carry load in

two different configurations and analysed the impact it had on the human

musculoskeletal structure. The research concluded that with increasing load, the gait,

and the body posture of the individual changes significantly irrespective of the load

lifting configuration. It was also concluded that the chance of encountering injuries due

to stress was also possible.

Another study by Hayder F N Al Shukla et. al discusses how improper manipulation of

heavy weights can lead to experiencing hard stresses throughout the human body. The

lower spine is commonly considered the most susceptible region to be affected by lifting

heavy weights. The paper also discusses the biomechanical modelling and the multi-

level control strategies that must be deployed to reduce the force wrench and achieve

better trajectory. The research work concludes that for an exoskeleton system, the user

intention has to be identified, minimize the human-machine interaction, estimate the

interaction force wrench for control purpose, and finally determine the power

compensation that the exoskeletal system has to provide to compensate for the lacking

effort.

### 2.2 Gait study

Martin et. al worked extensively in the field of gait analysis have done significant and

impactful contributions in the field. The work complied gait data for people of different

age groups performing activities. The paper presented the angular positions, angular

velocities, and acceleration data values to name a few for the hip joint, knee joint and

ankle joint. Collection of this data allows the quick visualization of the gait pattern and

deployment of control strategies on an exoskeleton.

Humans’ gait patterns are based off dynamic balanced gait and on the other

exoskeletons are based off statically balanced gait. The difference between human and exoskeleton gait will give path to interesting modelling of the gait of the exoskeleton.

(Barbareschi G, 2015).

### 2.3 Design considerations for Exoskeleton

### 2.3.1 Actuator

Lower Limb exoskeletons are actuated predominantly in three types, i.e. active, passive,

and quasi passive assistive actuation, and hybrid actuation.

Exoskeletons that are actuated with powered components such as motors, hydraulics or

pneumatics are considered active actuation. When passive elements such as springs are

used that stores energy, the stored energy can be used to actuate the system. Such

systems are referred to as passive actuation systems. These systems use gravity to

achieve balance. Quasi passive actuation systems work in conjunction with viscosity

devices like clutch-damper configurations (Sai K. Banala, 2006). Hybrid systems work

in a combination of active passive, or active quasi passive system (Conor James Walsh,

2007).

### 2.3.2 Degree of Freedom

The complexity of the lower limb exoskeleton system can be attributed to the DOF of

the system. The DOF of a lower limb exoskeleton is defined as the number of

independent ways a joint can move. The maximum degree of freedom for a human leg

is considered 7. The thigh has 3 DOF, knee has 1 DOF and ankle joint consists of 3

DOF summing up to 7 degrees of freedom. (Zhiguo Feng, 2007).

### 2.4 Control Strategies

Exoskeletons are complex systems that demand multi-level control strategies for the

smooth operation. Generally, there are three levels of hierarchical controllers. These

controllers are namely the high-level, mid-level and low-level controllers (Norazam

Aliman, 2017). The highest-level controller determines the intention of the human being

and calculates the joint angles corresponding to that intention of motion. Once these

angles are computed, these values are passed down to the mid-level controller that send

pulses to the low-level controller that is directly linked to the actuator. The low-level

controller ensures that the actuator reaches the desired final set point. With this overall

structure, different control strategies are used to determine the intention, the pulses to

be sent to the low-level controller (Michael R Tucker, 2015).

CHAPTER 3

BASIC CONCEPTS AND REPRESENTATION

In this chapter some of the basic notions and terms associated with the area of

exoskeleton will be presented. All the terminologies that will be used throughout in this

thesis will be covered. This allows a common understanding and lucid understanding

of the terms that are being used.

### 3.1 Representations

It is necessary to define how the coordinates are represented. The global frame is a right-

handed coordinate system with the directions of the axis as shown in the figure. The

coordinate axis is aligned such that the X-axis is aligned in the walking direction. The

analysis of an exoskeleton is easier in the orthogonal planes and are planes are named

the following:


XY plane – Transverse plane

XZ plane – Sagittal plane

Figure 3.1: Planes of analysis.

YZ plane – Frontal plane

### 3.2 Gait Terminology

### 3.2.1 Robotic Locomation

This section is mainly based on (M. Vukobratovic, 2006) who have made great

contribution towards the unification and standardization in robotic locomotion. The

terms that are related to robotic locomotion are:

Walk: Defined as movement by putting forward each foot into turn and not moving

both feet of the ground at once.

Gait: Defined as the manner of walking hence when an exoskeleton is used to walk it

can have several different gates. If a vector θ(t) is defined to contain all the joint angles,

then a time history of θ(t) represents a specific gait.

Step: A step is defined as in: the direction of motion during the contact with the ground

the leg from the front position with respect to the trunk comes to the rear position then

it is deployed from the ground and in the transfer phase move to the front position to

make again contact with the ground and the cycle is repeated.

Periodic Gait: A gait is periodic if the same step is repeated after a fixed interval of

time, thus if θ(t) = θ(t+T) implies that the gait is preriodic with period T (one step

duration).

Symmetric Gait: A gait is symmteric if the step can be divided into two equal time-

periods such that the right leg behaves as left leg in the other period and vice versa.

Thus if θR(t) = θL(t + T⁄2), where θR is the joint angles of the right leg and θL is the

joint angles of the left leg, the gait is said to be symmetric.

Trajectory: A trajectory is the path of a moving point in the three dimensional space.

In gait analysis, trajectories are used to describe the movement of a joint frame, relative

to the global reference frame, which is usually atttached to the ground.

### 3.2.2 Walk Cycle

The walk cycle as described in (Walter Pirker, 2016) consists of the following important

phases, the swing phase and the stance phase.

Stance phase: It constitutes approximately 60% of the gait cycle. Both feet are in

contact with the ground at the start and the end of the stance phase. It can be further

subdivided into the following:

i. Heel Strike – initial contact

ii. Mid – stance

iii. Terminal Stance

Swing phase: It consititutes the other 40% percent of the gait cycle and it can be

subdivided into the following:

i. Toe – off – initial swing phase

ii. Mid – swing

iii. Terminal swing


### 3.3 Brushless DC Motor and its Controller

### 3.3.1 Advantages of choosing Brushless DC Motor

Exoskeletons can be actuated using brushless DC motor as they have the following

characteristics.

1) BLDC motors have inherently higher torque than their counterparts in similar

voltage range without an additional transmission system.

2) They are back-drivable and can be suitably damped electronically to mimic

human joint behaviour.

Figure 3.2: Phases of walking cycle. Source - (Walter Pirker, 2016)

3) BLDC motors usually have hall sensors inside the motor housing that trigger

output when the rotor passes over them in specific position. This inbuilt addition

allows for deployment of better control architecture deployment.

4) BLDC motor have electrical commutator as compared to mechanical

commutator in brushed DC motor. This gives the following advantages.

a. Longer lifetime because of reduced wear and tear.
b. Minimized losses due to frictional losses and heat losses.
c. Higher switching frequency which allows for lower noise.

### 3.3.2 Control of BLDC Motor

### 3.3.2.1 ESC

Electronic Speed Controllers (ESCs) regulate the speed of Brushless DC (BLDC)

motors by adjusting the voltage provided to the motor's coils. from the MOSFETs by

changing electrical signals at a constant frequency.

ESCs use PWM signals from a microcontroller or receiver to control motor speed. The

PWM signal's duty cycle (ratio of ON time to the total period) determines the average

voltage supplied to the motor. BLDC motors have three coils, and the ESC sends signals

to energize each coil in a sequence, creating a rotating magnetic field. By varying the

timing and duration of these signals, the ESC controls the motor's speed and direction.

Advanced ESCs incorporate feedback mechanisms such as Hall Effect sensors or back

electromotive force (EMF) sensing to precisely regulate motor speed and provide

features like smooth acceleration, braking, and even reverse operation.

### 3.3.2.2 Torque Control on a BLDC Motor

In a BLDC motor, the current (directly corresponds to the torque output) is typically

controlled through a closed-loop control system employing PWM techniques. This

control system utilizes feedback from current sensors, such as shunt resistors or Hall

effect sensors, to monitor the current flowing through the motor windings. The control

algorithm calculates the difference between the desired current reference and the actual

measured current, generating an error signal. This error signal is then used to adjust the

duty cycle of the PWM signals applied to ESC. By modulating the duty cycle of the

PWM signals, the controller regulates the average voltage applied to the motor

windings, thereby controlling the current flow.

The torque of a BLDC motor is given by the equation (Sul, 1995):

τelec =

eaia + ebib + ec

ic
ωm

Where, ea, eb, ec are Back EMF’s and ia, ib, ic are currents in each phase.

### 3.4 Communication Protocols

In a complex robotic system such as an exoskeleton, high processing power is

mandatory. In the event of lack of processing power, multiple microcontrollers are used

to decentralize the control flow and distribute processing power. On such occasions, it

is of prime importance that the compute units can communicate with one another

effectively. Communication protocols such as UART and I2C are used primarily in these

circumstances.

### 3.4.1 Universal Asynchronous Receiver and Transmitter (UART) Protocol

UART is the simplest form of serial communication. It has a transmitter and receiver

line that send and receive bits respectively (Durda, 2021). It is called an asynchronous

line as there is no clock signal line that time syncs the data sent/received. The bits are

sent based on the “baud rate,” the frequency at which the bits are sent in that channel.

A baud rate of 9600 implies that the microcontroller will read data on the

communication line at a frequency 9600 Hz. The timing of reading, once set, is executed

based on the internal crystal oscillator pulse timings. Depending on the number of

communication lines, UART is classified into 3 types:

A. Simplex – This configuration has only one data line and the sending or receiving

bits happens in the same line. The data can be sent only in one direction.


Figure 3.3: Configurations of UART communication.

B. Half Duplex – There is a single line for transmitting and receiving respectively

but one of the two microcontrollers can use the communication line at a given

point in time.

C. Full Duplex – There are two communication lines TX and RX and

simultaneously sending and receiving across these lines are possible.

### 3.4.2 I2C Protocol

The Inter-Integrated Circuit (I2C) protocol is a serial communication standard used to

connect microcontrollers and peripherals, enabling bidirectional data transfer over a

two-wire interface. Devices are distinguished by unique addresses, facilitating

communication between multiple components on the same bus. Communication occurs

via a master-slave architecture, where a master device initiates data transfer and controls

the bus, while slave devices respond to commands. There are two lines, the SDA (the

data line) and SCL (the clock line). The communication protocol is considered

synchronous as there exists clock line that maintains the synchronism. The data on the

data line from each bit is read against the rising and falling of the clock line pulses.


Figure 3.4: I2C Line Configuration

CHAPTER 4

EXPERIMENTAL SETUP

### 4.1 Elements required for an Exoskeleton System

The following aspects are needed in an experimental prototype of an exoskeletal

system:

### 4.1.1 The Actuators

As previously discussed, using an active exoskeleton augments the user's strength. As

such, the actuators in any exoskeleton play an extremely crucial role in the functioning

and will be chosen with extreme consideration.

Table 4.1: Comparison of Pneumatic/Hydraulic actuators vs Motors
Pneumatic/Hydraulic Actuators | Motors
Typically, the motion caused by them is linear. | The motion caused by them, transmitted from the shaft is rotational.
Joint angles are changed by arranging in a 3-bar mechanism with a link having variable length. | Joint angles are changed by actuating the motor, in turn causing rotary motion directly.
The gas/oil in the system tends to leak out thus dirtying workspace and needing replenishment. | They need batteries to be powered. They do not have any consumable/perishable elements in construction.
They are robust in nature and can withstand impacts from objects and environment. | They are delicate and cannot withstand impact from surroundings, especially with encoders or other sensitive elements.
They are easier to maintain and service and are cheaper. | They are more expensive to service and repair. The initial investment is lower.

### 4.1.2 The Sensor Suite

For proper control and functioning of an exoskeleton, the sensor systems become the

core in obtaining and sending feedback based on which the system's actions will be

decided. The following are the kinds of feedback needed, the corresponding sensors for

the same, typically used in an exoskeleton:

a. Angular position
i. Rotary encoders (at joints)

ii. Potentiometers (at joints)

iii. Accelerometers/IMUs (on links)

b. Contact Forces (typically at locations like finger pads and under the sole)
i. Force Sensitive Resistors (FSRs)

ii. Strain Gauge

c. Neuro-muscular signals
i. EMG (muscle activity detection)

ii. EEG (cerebral activity)

Angular positions (and higher order terms - velocity and acceleration) are taken as

feedback for control algorithms to close the loop. At the same time, combinations of

inputs from contact forces and neuro-muscular signals will yield appropriate

activity/intention detection and, as such, are used in action planning.

### 4.1.3 Computational Unit

The feedback from the sensor suite must be processed into meaningful outputs and used

to provide the inputs corresponding to the system's necessary actions. This raises the

requirement of a unit that can be interfaced with both the sensors and actuators while

performing the necessary computations to plan the action sequence of the system and

transmit the same to the actuators. For this task, a microcontroller is used as it is

sufficiently low level to communicate with peripherals while also being able to perform

minimal necessary computation.

### 4.1.4 The Frame

The frame is the collection of links and other entities that hold all the sensors and

actuators together. The frame also consists of all the load-bearing entities (the links

connecting the joints) and the harness that connects the wearer to the links (the lumbar

support for the spine, the pads for the thigh, and the shank).

The lumbar support is a vital element in the frame, where the wearer is hung, and the

exoskeleton is grounded to the human. This supporting link also serves as the start in

the chain of links that serve as an alternate load path for the user's weight to the ground.

As such, the support and the harness should be designed to cover a broader area to decrease the pressure on the wearer at the regions of contact as it bears the user's weight

when hung.

### 4.2 Calculations and Considerations

### 4.2.1 The Frame

The links connecting the motor will be loaded with a bending moment during the entire

range of motion. As such, they must be able to withstand the bending load. The design

must be optimized to be minimal to ensure that the actuator can support the structure

and the user in the desired manner.

Most of the frame elements are made from aluminum, and the interfaces to the motors

are made of Delrin, ensuring that the structure has low weight and that the motors

require lower torques.

Assumptions for calculations of bending moment:

i. The links are treated as cantilever beams, hanging from one end (from the motor

end).

ii. Loads acting on them are not continuous and are point loads. The location of point

load acting is the centre of mass of the system of elements considered.

iii. Self-weight of the links has been excluded from the calculation as they are close to

2% of the weight of the user’s body part at the same location.

iv. For calculation of bending load, the links are assumed to be in a horizontal position

so that the bending load is maximized on the system.
v. The acceleration due to gravity is taken as 9.8144 m/s²
, and the Elastic Modulus (E)

of Aluminum as 70 GPa.

Bending Moment Calculations (ExRx, n.d.) (Robert V. Schulte, 2023)

i. Shank:

Dimensions of shank link: 400mm x 50.8mm x 0.6mm

Mass of Shank (mshank) = 3.336kg

Mass of foot (mfoot) = 0.971kg

Distance of the centre of mass of shank from point of rotation (lshank) = 0.21m

Distance of the centre of mass of foot from point of rotation (lfoot) = 0.45m

Distance of the centre of mass of foot and shank (combined) from point of rotation:

lcom =

(msℎank ∗ lsℎank) + (mfoot ∗ lfoot)

msℎank + mfoot

lcom = 0.264m

Load (F) = mcom*g = 42.27 N

Polar moment of inertia (I):

I =

l ∗ b ∗ (l

2+b

2
)
12 m⁴

I = 16090*10⁻⁹ m⁴

The maximum deflection in the beam due to bending load δmax, for a load acting at

x from supported end:

δmax =

F ∗ x

2 | ∗ (3L − x)
6EI
From above equation, values and with x = lcom, δmax = 0.0408 µm

ii. Thigh:

Dimensions of thigh link: 400mm x 50.8mm x 0.6mm

Mass of Thigh (mthigh) = 10.563kg

Mass of Motor (mmotor) = 1.4kg

Mass of Shank (mshank) = 3.336kg

Mass of foot (mfoot) = 0.971kg

Distance of the centre of mass of thigh from point of rotation (lthigh) = 0.206m

Distance of the centre of mass of motor from point of rotation (lmotor) = 0.4m

Distance of the centre of mass of shank & foot from point of rotation (lshank) =

0.667m

Distance of the acting centre of mass from point of rotation:

lcom =

(mtℎigℎ ∗ ltℎigℎ) + (mmotor ∗ lmotor) + (mcom_sℎank ∗ lcom_sℎank)

mtℎigℎ + mmotor + mcom_sℎank

lcom = 0.3444m

Load (F) = mcom*g = 159.41 N

Polar moment of inertia (I):

I =

l ∗ b ∗ (l

2+b

2
)
12 mm⁴

I = 6817.5*10⁻⁸ mm⁴

The maximum deflection in the beam due to bending load δmax, for a load acting at

x from supported end:

δmax =

F ∗ x

2
∗ (3L − x)
6EI
From above equation, values and with x = lcom, δmax = 0.29 µm

From calculations, it is observed that the deflection in the links on full loading is in the

order of micrometres, which is negligible. As such, it is concluded that the setup is safe

to test, load and execute experiments on without leading to failure.

### 4.2.2 Motors

The significant factors that help decide the actuator specification for the system are the

joint torques and speed, i.e., the motor's power. For the exoskeleton to trace the

necessary gait, it must be able to move loads at necessary speeds to achieve needed

positions. For this set of calculations, the static torque is calculated for holding a specific

pose, and it is multiplied by a factor of safety to account for its functioning in dynamic

conditions.

τknee =

(msℎank) ∗ g ∗ lsℎank ∗ sin θknee
2

τℎip = [(mmotor +

mtℎigℎ
2

) ∗ g ∗ ltℎigℎ ∗ sin θℎip]

+ [msℎank ∗ g ∗ (ltℎigℎ ∗ sin θtℎigℎ +

lsℎank ∗ sin θknee
2

)]

The parameters are the same as considered for the bending moment calculations, with

the addition of angles. The maximum condition for thigh is both thigh and knee angle

being at 37°, while for shank it is 45°.

From above equations and parameters, the τknee = 5.17Nm, and τhip = 30.14Nm.

Considering a factor of safety of 2 and a speed of 10 rpm at the described position, the

maximum power needed will be:

Pmax = τℎip ∗ ω ∗ FOS

Pmax = 60.28W

Nominal Motor Power Output from datasheet = 197.88W. From this, it can be

conclusively said that the motors can handle human loading within all working angle

ranges required to demonstrate human gait.

### 4.3 Setup Description

The experimental setup used consists of the following:

### 4.3.1 Frame

The frame has links made of aluminum, and the mating structures to the motors made

of Delrin were designed to handle the bending and shear loads acting on them

sufficiently.

### 4.3.2 Motor and Controller

The motors used are Maxon EC-φ90 flat BLDC motors with hall sensors and built-in

encoders. The specs of the motor are as follows:

1. Working Voltage: 48V
2. Nominal Torque: 964 mNm
3. Nominal Current: 4.06 A
4. Gearbox Knee: 36:1
5. Gearbox Thigh: 60:1
6. Encoder Resolution: 4096 pulses per revolution

The motor, along with the motor controller ESCON Module 50/8, can operate with up

to 15A of current. The motor controller can operate with a two-channel double-ended

encoder input, hall sensor inputs from the motor, and an internal controller to perform

accurate current and speed control on the motor [Appendix A].

### 4.3.4 Wiring

All the power lines are wires of 16 AWG, which can comfortably conduct a current of

13A without overheating. Furthermore, the data cables are wires of 22AWG, which can

lower the losses during conduction.

Switches of appropriate ratings have been chosen on each of the power lines: 20A for

the motor and 6A for the buck converter (which powers the compute element).

### 4.3.5 Sensors

Four 9-DOF IMUs, BNO-055, are used as sensors to close the control loop. The IMU,

chosen for its sensor outputs, can give acceleration, gyroscope, magnetometer, and other

readings [Appendix B] over I2C to a master controller. Gravity readings are processed

to obtain the information needed for motor control.

### 4.3.6 Compute Element

An ESP32 Devkit, based on Espressif's ESP32 series microcontroller, is used as the

main compute element. It was chosen based on clock speed, support with peripherals,

PWM, I2C, UART, and Digital I/O capabilities.

A PCB has been designed to minimize the exposed ends and to turn the system into a

singular embedded autonomous module. [Appendix C]

CHAPTER 5

RESEARCH METHODOLOGY

### 5.1 Control System Design

### 5.1.1 Current Control Strategy

The current traveling across a shunt resistor on an excited phase is measured and

compared against the setpoint value. If lower, the motor coils are excited with a higher

voltage. The coils' excitation voltage is lowered if the current is higher than the setpoint.

This simple change in current translates to a more complicated kinematic change from

the standpoint of position control.

The electromagnetic torque of a BLDC motor is given by the equation (Sul, 1995):

τelec =

eaia + ebib + ec

ic
ωm

Where, ea, eb, ec are Back EMF’s and ia, ib, ic are currents in each phase. At any given

time, one of the three windings will be given the positive voltage and one negative,

which completes the circuit. Since the same amount of current (with no accumulation

of charge at any point, by Kirchoff's Current Law) passes through to complete the

circuit, it can be extrapolated that the phase currents between the running phases will

be equal. The sum of back emf between the two phases will amount to the voltage

difference, V, provided by excitation. Thus, the relation evolves as follows:

τelec =

V ∗ i

ωsℎaft

For a simple system of a link fixed at a point, free to rotate in the vertical plane, the

relation between the mechanical torque and the angular position (θ, with respect to

vertical) is:

τmecℎ = mlink ∗ g ∗ llink ∗ sin θ

During the functioning of the motor, the electromagnetic torque output is equal in

magnitude to the demand mechanical torque. Similarly, the shaft angular velocity is the

same as the angular velocity of the link. From the above two torque equations, the

relation between current and angular position is:

i =

mlink ∗ g ∗ llink ∗ sin θ ∗ θ̇ V

Combining all the constant terms into an arbitrary term, λ, the current required for the link to be at a specific angular position θ and having angular velocity θ̇ is given by:

i = λ ∗ sin θ ∗ θ̇

In practice, the equation would not end as shown above due to non-linearities or noise

accumulated in the response through the whole system's functioning. As such, the

equation would be:

i = λ ∗ sin θ ∗ θ̇ + b

Where, λ is a constant close to (mlink ∗ g ∗ llink) but not equal, and an additional

constant bias term b is introduced to account for offsets. Different input signals must be

given to the motor to observe the response of the system at various angular positions

and time instances to be able to accurately model the system equation.

Accounting for the inrush current factor (for the start of the actuation of the motor) and

penalizing error of angular position and velocity. A modified version of PD controller

with model information can be used:

i = f(θ, θ̇) + (Kp ∗ ∆θ) + (Kd ∗ ( d(∆θ)

dt − ωθ))

This control equation can be interpreted as:

i. When desired angular velocity and position are reached, the other terms tend to
0. As such, the system is supplied the current of value f(θ, θ̇), corresponding to

the current necessary to be at angular position θ, with the angular velocity θ̇
ii. | The (Kp ∗ ∆θ) term, is the proportional term from the proposed addition of PD
| controller, serves two distinct and important purposes. This helps in the system
| reaching the setpoint position quickly and as an inrush current factor (for the
| motor to begin actuation).

iii. The (Kd ∗ (
d(∆θ)
dt

− ωθ)) term, is the derivative term, also serves two purposes.

| It acts as a higher order proportional term (for angular velocity), and acts as a
| dampening factor for oscillations against angular position.

Reference Signal (θ, θ̇); Feedback Signal (θ, θ̇); Actuation

The above control equation is obtained by treating the system as a second order system,

and while using only zero and first order inputs. Additionally, second order inputs can

be added to the equation, resulting in a control scheme that can minimize fluctuations

in angular velocity while also allowing to achieve desired angular acceleration.

### 5.1.2 Speed Control

Traditionally, speed control is done using feedback from sensors such as optical

incremental, absolute encoders, or hall-effect sensors. In this, a voltage is given for coil

excitation while measuring the speed of the motor shaft against the setpoint value. If

lower, the motor coils are excited with a higher voltage. The coils' excitation voltage is

lowered if the speed exceeds the set point. This scheme is more straightforward to

execute for the position control task since the change is directly reflected in the form of

a kinematic entity that is also being controlled.

Since the kinematic entity is being controlled, angular velocity (θ̇) is an order of

magnitude higher than the target variable (θ). So, a simple PD control scheme can

perform the necessary position control task. As such, the control equation will be:

ω = (Kp ∗ ∆θ) + (Kd ∗

d(∆θ)
dt )

Figure 5.1: Current Control

### 5.1.3 Control Scheme

The goal of achieving a set target position can be achieved through the above mentioned

two control modes (configurable and usable via ESCON Module 50/8 motor controller).

As such, a study of formulation of the execution method was done to conclude that a

speed-based position controller is optimal for deployment at the beginning stage of

testing and research.

The position controller used in practice for the thesis does not have a derivative term

since the ESCON Module’s internal speed controller [Appendix A] can accurately

achieve setpoint angular velocities, and the controller response (slow or stiff)

is configurable. Thus, the control equation is:

ω = (Kp ∗ ∆θ)

Reference Signal (θ); Feedback Signal (θ); Actuation

### 5.1.4 System Inputs and Outputs

From the above controller equation, the following information can be gathered:

i. The controlled quantity is the angular velocity of the shaft.
ii. | The target quantity is the angular position of the shaft, and the error is computed
| based on the deviation from the setpoint.

From the above information, the inputs to the controller are:

i. Reference Signal: This is the setpoint, or the target position, to be achieved.
ii. | Angular Position: This is the real-time angular position of the shaft in the
| vertical plane, based on which the error is computed.

Figure 5.2: Speed Controller

The controller output will be the angular velocity value for the motor to achieve the

desired position based on the configured response characteristic.

### 5.1.5 System Constraints

The system and controller are operated under the following constraints:

i. Maximum allowed angle for the thigh during the gait cycles is 25° from the

vertical.

ii. | Maximum allowed angle for the shank during the gait cycles is 37° from the
| vertical.
iii. | The maximum allowed angular velocity for any link is 10 rpm. As such, the
| maximum permissible speed for hip and knee motors are 600 and 360 rpm,
| respectively.
iv. | Maximum permissible current draw per motor is limited to 15A.
v. The control frequency is restricted to 20Hz, for the initial stages.
vi. | The maximum angle difference for a link between any two consecutive setpoints
| should be no more than 15°.

### 5.2 Elements of the control system

From the above control block diagram representations, the following are functional

elements on which computation is performed.

### 5.2.1 Feedback

Feedback is an essential component of a closed-loop control architecture, as the

subsequent future output of the system is based on its current state. As mentioned in

Section 4.3.5, BNO-055 was used as the feedback element for the position controller.

The IMU can provide gravity outputs on its X, Y, and Z axes. The value of the angle

from the vertical is obtained by using the following relation:

θ = tan⁻¹

gx
gy

### 5.2.2 Controller

The error is computed by comparing the feedback against the setpoint value. Then, it is

multiplied by a proportional gain (KP) to get the controller output. This output is

mapped to an integer of 102 to 922 (10-90% duty cycle, on 10-bit resolution) to be

given as input to the ESCON Module 50/8.

The higher the KP value, the higher the speed at which the angular position is

approached. This value determines the response speed of the controller. Very low KP

value means that the system takes a very long time to reach the setpoint while a very

large setpoint means that the rate of change of angular position and velocity will be very

high. This will cause unwanted jerks and disturbances in the system and is to be avoided.

An ideal method to tune the value is to use the method of averages against the metric

being desired reaching and settling time from one setpoint to another.

### 5.3 Controller Tuning

The position controller design, tuning, and implementation were done in stages to allow

sufficient time for system behaviour analysis during deployment, to avoid accidental

damage to equipment. The deployment on the system has been in the following order:

### 5.3.1 Single Actuator System

The controller design began with verifying checks of angular position feedback

robustness. This was performed throughout the working range of the shin link, and

outliers were handled to ensure consistent and reliable outputs were given to the

controller.

The knee motor was set to operate on its nominal current 4.06A, as the datasheet

provided. The speed was limited to 108 rpm during the testing phase, resulting in 3 rpm

on the output shaft. The internal current and speed (closed and open loop)

controllers were tuned using the auto-tuning package provided by the ESCON Studio

application, with inputs for direction and speed control configured on both the receiving

motor controller end and pins set for output and duty cycling on the MCU.

The knee motor was mounted on a table with various setpoint angles given while

changing the gain on the controller. This activity was performed iteratively following

the method of averages to reach the ideal KP value for the desired settling time.


### 5.3.2 Dual Actuator System – Single Leg Motion


The robustness check of the data stream from the IMUs was redone, with checks for

crosstalk between the data on the bus. Stress tests were done to check the highest

sampling and compute the IMU and MCU combination frequency against the desired

control frequency to isolate the lagging element. The processed output data stream had

an ODR of over 100Hz, which proved sufficient to deploy with controllers. As such,

the control algorithm was deployed.

The hip motor was set to operate on a nominal current of 8.00A, as the joint needed to

output higher nominal torque than the knee joint. The speed was limited to 120 rpm for

the testing, resulting in 2 rpm on the output shaft. The internal current and speed (closed

and open loop) controllers were tuned using inputs and pins for direction and speed

control configured on both the receiving motor controller end and the MCU.

In this case, all the load was unmounted from the shaft of the hip motor during the auto-

tuning sequence as it could cause unwanted noise during the software’s internal current

Figure 5.3: Shin link position control demand and speed actual sampling. High-frequency angular vibration, caused as part of

the auto-tuning routine, on objects (the links and attached motors) with heavy inertia

will draw dramatically higher currents than needed and could potentially damage the

gears on the transmission line.

The knee motor was mounted back on the hanging exoskeleton setup to the end of the

thigh link. Specific setpoint angles were given while changing the gain on the controller

till the ideal KP value was reached. Post controller tuning, angles of specific

stances were fed as input to validate that the overall system was working.


### 5.4 Gait Pattern Data

Schulte et al., 2023 generated a database detailing the kinematics of the lower extremity

during gait related actions in able-bodies people. The gait data of one individual from

the given sample set was taken, for the implementation of the thesis work.

The data points of each subject had outputs of angular position, velocity, acceleration,

muscular and electrical activity, joint torques of the hip, knee, and ankle joints at a

frequency of 1000Hz collected for a time interval of 70 seconds.

Figure 5.4: Overall control architecture.


### 5.4.1 Isolation of Single Step Motion Data Points

The graphs of the angular position data of the thighs and shanks were visualized to

isolate the sequence of angles of a single step taken by the subject. The data was

subsequently processed to isolate a set of 21 angles from the original 1000 data points,

ensuring no significant losses in graph definition. The following are the plots of the 21

angles of each limb against time:

Figure 5.6: Single gait cycle plot

Figure 5.5: 2 DOF single leg gait cycle

### 5.4.2 Dataset Augmentation and Visualization

The data points collected by Schulte et al., 2023 were that of humans with normal

flexibility and no specific motor function restrictions. This data cannot be translated as

is into the exoskeleton's working due to constraints imposed by the design of the setup.

The knee joint has a guard tab that restricts that motion to prevent damage to the user's

knees and not rotate into an angular position that is not humanly achievable. This guard

tab also imposes an additional angular constraint that the minimum difference between

the angles of the links should be 9 degrees. Hence, the dataset was augmented with this

condition being the front-runner and shifting from the coordinate frame from the one

Schulte et al., 2023 operated on to which the exoskeleton is calibrated. This angle

sequence was also visualized using a Python script [Appendix F]

### 5.5 Continuous Gait Motion

Implementing a continuous gait trajectory means that the links must attain and move

through the specific trajectory point sequence. As such, it is crucial to understand and

define what it means to reach a position to the controller since the system's response is

transient. Furthermore, all the work discussed in the previous sections was executed on

a single leg. Time synchronization between the motion of the two legs is of paramount

importance as asynchronous motion will not result in a replication of human gait but

would cause the user to fall.

### 5.5.1 Position Attainment Condition

Since the working of the system is not completely predictable, placing a trigger within

a region of tolerance from the target angle to act as a check measure of pose attainment

is not the right approach. Experiments were conducted where a specific set

of angles were fed as setpoints, and the system's response was observed. It was

noted that the system reaches the setpoints within roughly 20% of the settling time but

would fall out of the tolerance region at roughly about 50% of the settling time. This is

because the thigh link moves because of the change in the angle of the shank and,

subsequently, the torque required. So, at a particular instant, the torque demand would

not match the supply. This causes an undershoot or overshoot of the position. To avoid

the transient response conditions, the system's settling time is observed for a few repetitions of the experiment, and a timer is used as the metric to determine the change

in setpoints.


Table 5.1: System Behaviour w.r.t time

### 5.5.2 Time Synchronization

The mid-level controllers are executed using the ESP32D as the core processing

element. Both legs’ ESP32s work on the same internal clock frequency of 80MHz. As

such, time synchronization of their action execution can be crudely achieved by having

both processors begin operating at the same point in time. For this, one of the MCUs

can exit its set up and be put to wait indefinitely for an acknowledgment handshake

from the other MCU. The sender MCU will be transmitting the handshake and

subsequently begin working with no delay. The receiver, on receiving, immediately

begins working. A transmission delay, if it occurs, can be digitally compensated on the

sender end to ensure synchronicity.

CHAPTER 6

RESULTS, CONCLUSION AND FUTURE WORK

### 6.1 Results and Conclusion

The following are the results achieved:

i. Low-level current and speed controllers have been configured for the BLDC

motor control.

ii. | A novel model-based current control architecture has been theorized, and the
| method of deployment has been elaborated.
iii. | Mid-level position control based on a Proportional Bang-Bang controller has
| been deployed and tested.
iv. | System was studied and an open loop feedforward controller has been deployed
| and verified for changing the setpoints to achieve continuous motion.
v. Time Synchronization in working of multiple controller units has been ideated,
| executed, and validated.

The following conclusions can be drawn from the research:

i. Repeating gait cycles and achieving poses is task that should be handled in
| parallel for multiple DOF systems. Microcontrollers with more than one core
| should be employed for the task of position control, with each core monitoring
| one motion.
ii. | A speed-based control, although easier to deploy, is not the most robust solution
| to the position control task. This is due to the absence of an element of
| impedance control or a direct torque-based input. As such, it is advisable to work
| on current based control approaches.

### 6.2 Future Work

Developments that can be made to the existing test bed involve robust control

architecture based on current control of motors can lead to precise control over the

variables such as angular acceleration, position, and velocity. A sensor suite of IMUs

can be used to detect the intention of the user and determine the joint angles for the gait appropriately. Precise intention detection is possible with the help of EMG sensors that

give data on the muscle activity.

CHAPTER 7

REFERENCES

Al-Shuka, H. &. (2019). Biomechanics, actuation, and multi-level control strategies of power-augmentation lower extremity exoskeletons: an overview. International Journal of Dynamics and Control, 1462-1488.

Barbareschi G, R. R. (2015). Statically vs dynamically balanced gait: Analysis of a robotic exoskeleton compared with a human. 37th Annual International Conference of the IEEE Engineering in Medicine and Biology Society (pp. 6728-6731). IEEE.

Conor James Walsh, K. E. (2007, March 8). A Quasi-Passive Leg Exoskeleton For Load-Carrying Augmentation. International Jounral of Humanoid Robotics, pp. 487-506.

Dasari Karthik, C. K. (2022). Identifying the significant factors affecting the masonry labour productivity. Internal Journal of Construction Management, 464-472.

Durda, F. (2021). Serial and UART Tutorial. FreeBSD Foundation.

ExRx. (n.d.). Body Segment Data. Retrieved from ExRx.net: https://exrx.net/Kinesiology/Segments

H. Kazerooni, J.-L. R. (2006). On the Control of the Berkeley Lower Extremity Exoskeleton (BLEEX). Proceedings of the 2005 IEEE International Conference on Robotics and Automation. Berlin: IEEE.

Hao Lee, P. W. (2019). Lower Limb Exoskeleton Systems—Overview. Wearable Robotics.

Kinoshita, H. (1985). Effects of different loads and carrying systems on selected biomechanical parameters describing walking gait. Ergonomics, 1347-1362.

M. Fontana, R. V. (2014). The body extender: a full-body exoskeleton for the transport and handling of heavy loads. Robotics and Automation, pp. 34-44.
M. Vukobratovic, B. B. (2006). Towards a unified understanding of basic notions and terms in humanoid. Robotica, 87-101.

Makinson, G. E. (1971). Research and Development Prototype for Machine Augmentation of Human Strength and Endurance: Hardiman I Project. The Company.

Martin Grimmer, A. A. (2020). Human Lower Limb Joint Biomechanics in Daily Life Activities: A Literature Based Requirement Analysis for Anthropomorphic Robot Design. Humanoid Robotics.

Michael R Tucker, J. O. (2015). Control strategies for active lower extremity prosthetics and orthotics: a review. Journal of NeuroEngineering and Rehabilitation.

Neumann, D. (2009). Kinesiology of the Musculoskeletal System: Foundations for Physical Rehabilition. Mosby.

Norazam Aliman, R. R. (2017). Design and development of lower limb exoskeletons: A survey. Robotics and Autonomous Systems, 102-116.

Robert V. Schulte, E. C. (2023). Database of lower limb kinematics and electromyography during gait-related activities in able-bodied subjects. Scientific Data.

Sai K. Banala, S. K.-L. (2006). Gravity-Balancing Leg Orthosis and Its Performance Evaluation. IEEE Transactions on Robotics (pp. 1228 - 1239). IEEE.

Sul, S.-J. K.-K. (1995, November 6). Direct Torque Control of Brushless DC Motor with Nonideal Trapezoidal Back EMF. IEEE Transactions on Power Electronics.

Vikash Kumar, Y. V. (2019). Review of Exoskeleton : History, Design and Control. 3rd International Conference on Recent Developments in Control, Automation & Power Engineering (RDCAPE) (pp. 677-682). IEEE.

Walter Pirker, R. K. (2016). Gait disorders in adults and the elderly. Wien Klin Wochenschr.

Yagn, N. (1890). US Patent No. 420179.

Zhiguo Feng, J. Q. (2007). Biomechanical design of the powered gait orthosis. IEEE International Conference on Robotics and Biomimetics (ROBIO) (pp. 1698-1702). Sanya: IEEE.

APPENDIX A

ESCON Module 50/8 Capabilities

The controller and motherboard can control BLDC motors up to a power rating of 260W

and can handle a maximum continuous current of 15A. It can take in the hall sensor and

encoder inputs (double-ended, up to two channels) from the motor to compute rotor

speed.


It has the following I/O capabilities:

i. Digital comparator outputs for current and speed.
ii. | Digital input duty cycle measuring capability.
iii. | Digital HIGH and LOW detection capability.

Figure A.1: Maxon controller schematic.

iv. | Analog output of real-time actual speed, control signal speed, demand current,
| actual averaged current, and temperature.
v. Single and double-ended analog signal input detection and scaling.

Control Schemes:

i. Current Controller
ii. | Speed Controller (Closed Loop)
iii. | Speed Controller (Open Loop)
a. Based on static IxR gain (reconfigurable)
b. Based on adaptive IxR gain

Debug and tuning capabilities:

i. A control scheme can be chosen, and the inputs specified. Once done, the
| controllers can be auto-tuned by an internal system identification routine, or
| manual parameter input-based expert tuning can be done.
ii. | Expert tuning can be done on the controller to adjust the controller's response
| from a slow response to a stiff response. A slider is given to choose the required
| damping of the control scheme.
iii. | An internal system diagnostics toolbox that checks individual motor subsystems
| is present and can be used over USB to detect failures, possible causes, and their
| fixes.

APPENDIX B

BNO-055

The IMU used is BNO-055, a 9-DOF IMU made by Bosch Sensortec. It has low gyro

drift with time and has reliable readings. It has an ARM Cortex-M0-based

processor that performs computations on the sensor readings, abstracts the sensor-fused

data into a class-based structure, and transmits the same via I2C/UART to a host

MCU/MPU. It outputs the following readings:

i. Absolute Orientation (Euler Angle Vector based on 360° sphere)
ii. | Absolute Orientation (Quaternion)
iii. | Angular Velocity Vector (rad/s)
iv. | Acceleration Vector (in m/s² )
v. Linear Acceleration Vector (in m/s²
| )
vi. | Gravity Vector (in m/s² )
vii. | Magnetic Field Strength Vector (µT)
viii. | Temperature (in °C)

APPENDIX C

Printed Circuit Board for the mid-level controller deployment

A PCB with a small form factor to be fitted with a mount on the links has been designed

around the ESP32-WROOM-32-UE module, chosen based on the requirements of

communication protocols, I/O pins, and compute ability to act as a mid-level controller.

The pins chosen were such that they had PWM and digital I/O capabilities with no

bootup glitches. Strapping and input-only pins were avoided. A USB-UART bridge was

added alongside debug status LEDs to allow for programming the board. The provision

for mounting a 48V to 5V buck converter to minimize the power sources used has been

given and routed to ensure good current carrying capacity. The following considerations

were taken during the design of the PCB:

- Delay matching on high-speed USB lines.
- Separating the clock and data lines of the I2C channel to avoid crosstalk.
- Copper pours, and thick traces for high current and voltage lines that can handle

more than 1A were included.

- Inclusion of screw holes, pluggable JST connectors, and screw terminal

positioning for ease of deployment on the user end.

- A MOSFET-based input power switching circuit has been provided to protect

parent device communication ports when programming the module.


Figure C.1: PCB Footprint


Figure C.2: PCB Schematic

APPENDIX D

Code for position control of single degree of freedom joint (shank)

#include <Wire.h>

#include <Adafruit_Sensor.h>

#include <Adafruit_BNO055.h>

#include <utility/imumaths.h>

#define BOOT 0

#define VOLTAGE 25

#define CW 19

#define CCW 5

Adafruit_BNO055 bno = Adafruit_BNO055(55, 0x28, &Wire);

double controller_output, current_angle, prev_error, curr_error, error_diff, set_point = 45;
double Kp = 2;
double Kd = 0;
int state = 0;

void setup() {
Serial.begin(115200);
while (!Serial) delay(10);

pinMode(CW, OUTPUT);
pinMode(CCW, OUTPUT);
pinMode(BOOT, INPUT);
if (!bno.begin())
{
Serial.print("Ooops, no BNO055 detected ... Check your wiring or I2C ADDR!");
while (1);
}

delay(1000);
}

void loop() {
sensors_event_t theta;
bno.getEvent(&theta, Adafruit_BNO055::VECTOR_GRAVITY); get_angle(&theta);

if (digitalRead(BOOT) == LOW) {
if (state < 2) {
state = state + 1;
}
else {
state = 0;

}
}

switch (state) {
case 0:
set_point = 45;
break;
case 1:
set_point = 135;
break;
case 2:
set_point = 60;
break;
}
controller();

int control_voltage = int(map(controller_output, 0, 720, 0, 255)); // Serial.println(control_voltage);
dacWrite(VOLTAGE, control_voltage);

prev_error = curr_error;
delay(10);
}

void controller() {
curr_error = set_point - current_angle; error_diff = prev_error - curr_error;

if (curr_error >= 0) {
digitalWrite(CW, HIGH);
digitalWrite(CCW, LOW);
}
else {
digitalWrite(CW, LOW);
digitalWrite(CCW, HIGH);
}

controller_output = abs((Kp*curr_error) + (Kd*error_diff));

}

void get_angle(sensors_event_t* event) {
double x = -1000000, y = -1000000 , z = -1000000; //dumb values, easy to spot problem
event->type == SENSOR_TYPE_GRAVITY;
x = event->acceleration.x;
y = event->acceleration.y;
z = event->acceleration.z;
if (abs(z) > 3) {

Serial.println("Please hold the mount vertical."); }
else {
if ((x < 0) && (y < 0)) {
current_angle = (atan(x/y) * 57.2957795131);
}
else if ((x < 0) && (y > 0)) {
current_angle = 180 - (atan(-x/y) * 57.2957795131); }
else if ((x > 0) && (y > 0)) {
current_angle = 180 + (atan(x/y) * 57.2957795131); }
else {
current_angle = 360 - (atan(-x/y) * 57.2957795131); }
}
}

APPENDIX E

Code for performing continuous motion on a two degree of freedom system (one full leg)

#include <Wire.h>

#include <Adafruit_Sensor.h>

#include <Adafruit_BNO055.h> #include <utility/imumaths.h>

#define SHIN_V 25

#define SHIN_CW 19

#define SHIN_CCW 23

#define THIGH_V 26

#define THIGH_CW 18

#define THIGH_CCW 4

const unsigned long stabilizing_time = 10000; //const unsigned long thigh_time = 10000; //const unsigned long shin_time = 9000; const int freq = 5000;
const int shinChannel = 0;
const int thighChannel = 1;
const int debugChannel = 2; const int resolution = 10;

unsigned long previous_time = 0;

double thigh_points[2] = {91, 105}; double shin_points[2] = {79, 75};
int i = 0;

Adafruit_BNO055 bno_thigh = Adafruit_BNO055(55, 0x28, &Wire); Adafruit_BNO055 bno_shin = Adafruit_BNO055(55, 0x29, &Wire);

double Kp_thigh = 2, thigh_controller_output, thigh_angle, thigh_error; double Kp_shin = 2, shin_controller_output, shin_angle, shin_error;

void setup() {
Serial.begin(115200);
while (!Serial) delay(10);

Serial.println("Setup initialized.");

pinMode(SHIN_CW, OUTPUT);
pinMode(SHIN_CCW, OUTPUT);

pinMode(THIGH_CW, OUTPUT);

pinMode(THIGH_CCW, OUTPUT);

ledcSetup(thighChannel, freq, resolution); ledcSetup(shinChannel, freq, resolution);

ledcAttachPin(26, thighChannel); ledcAttachPin(25, shinChannel);

delay(10);

Serial.println("Configured output and PWM pins.");

if (!bno_thigh.begin()) {
Serial.print("Problem with thigh BNO, rectify."); while (1);
}

if (!bno_shin.begin()) {
Serial.print("Problem with shin BNO, rectify."); while (1);
}

delay(10);

int setup_gap = 3;
while (setup_gap > 0) {
Serial.print("Setup complete. Executing loop in "); Serial.print(setup_gap);
Serial.println(" seconds");
delay(1000);
setup_gap = setup_gap - 1; }
}

void loop() {

controller();

delay(50);
}

void update_values() {

unsigned long current_time = millis();

if (current_time - previous_time >= stabilizing_time) { i = 1 - i;
previous_time = current_time;
}

}

void feedback() {
update_values();

sensors_event_t theta_thigh, theta_shin;

bno_thigh.getEvent(&theta_thigh, Adafruit_BNO055::VECTOR_GRAVITY); bno_shin.getEvent(&theta_shin, Adafruit_BNO055::VECTOR_GRAVITY);

thigh_error = thigh_points[i] - get_angle(&theta_thigh); shin_error = shin_points[i] - get_angle(&theta_shin);
}

double get_angle(sensors_event_t* event) { double temp_angle, x, y, z;
event->type == SENSOR_TYPE_GRAVITY;
x = event->acceleration.x;
y = event->acceleration.y;
z = event->acceleration.z;

if (abs(z) > 3) {
Serial.println("Please hold the mount vertical."); }
else {

if ((x < 0) && (y < 0)) {
temp_angle = (atan(y / x) * 57.2957795131);
}
else if ((x > 0) && (y < 0)) {
temp_angle = 180 - (atan(y / x) * 57.2957795131); }
else if ((x > 0) && (y > 0)) {
temp_angle = (atan(y / x) * 57.2957795131);
}
else {
temp_angle = 180 - (atan(-y / x) * 57.2957795131); }
}
if (temp_angle > 180) {
temp_angle = temp_angle - 180; }
return temp_angle;
}

void controller() {

feedback();

if (shin_error >= 0) {
digitalWrite(SHIN_CW, LOW); digitalWrite(SHIN_CCW, HIGH); }
else {
digitalWrite(SHIN_CW, HIGH); digitalWrite(SHIN_CCW, LOW); }
if (thigh_error >= 0) {
digitalWrite(THIGH_CW, LOW); digitalWrite(THIGH_CCW, HIGH); }
else {
digitalWrite(THIGH_CW, HIGH); digitalWrite(THIGH_CCW, LOW);
}

shin_controller_output = abs(Kp_shin * shin_error); thigh_controller_output = abs(Kp_thigh * thigh_error);

actuation();
}

void actuation() {
int shin_duty, thigh_duty;
if (abs(shin_error) > 2) {
shin_duty = int(map(shin_controller_output, 0, 240, 102, 922)); }
else if (abs(shin_error) <= 2) {
shin_duty = 102;
}

if (abs(thigh_error) > 2) {
thigh_duty = int(map(thigh_controller_output, 0, 240, 102, 922)); }
else if (abs(thigh_error) <= 2) {
thigh_duty = 102;
}

ledcWrite(shinChannel, shin_duty); ledcWrite(thighChannel, thigh_duty); }

APPENDIX F

Python Script for extraction and plotting joint angles from the dataset

import os
import h5py
import matplotlib.pyplot as plt
import numpy as np
import csv

# Path to data files

path = '../Gait Data'
subj = 'MP104.hdf5'

# Load file

hf = h5py.File(os.path.join(path,subj))

# Load data from one trial and plot labels trial = hf['Day_1']['Trial_01']

start = 30620
end = 31620

time = trial['Time'][start:end] - trial['Time'][start]

hip_l = []
hip_r = []
knee_l = []
knee_r = []
x_axis = []

for i in range(0, 1000, 50): hip_l.append(trial['Ang_Left_Hip'][start:end, -1][i]) hip_r.append(trial['Ang_Right_Hip'][start:end, -1][i]) knee_l.append(trial['Ang_Left_Knee'][start:end, -1][i]) knee_r.append(trial['Ang_Right_Knee'][start:end, -1][i]) x_axis.append(time[i])

hip_l.append(trial['Ang_Left_Hip'][start:end, -1][-1]) hip_r.append(trial['Ang_Right_Hip'][start:end, -1][-1]) knee_l.append(trial['Ang_Left_Knee'][start:end, -1][-1]) knee_r.append(trial['Ang_Right_Knee'][start:end, -1][-1]) x_axis.append(time[-1])

super_set = [hip_l, hip_r, knee_l, knee_r]

for set in super_set:
for i in range(len(x_axis)):

set[i] = round(set[i], 1)
for i in range(len(x_axis)): x_axis[i] = round(x_axis[i], 2)

csv_file = "new_angle_data.csv"
data = zip(x_axis, hip_l, hip_r, knee_l, knee_r)

with open(csv_file, 'w', newline='') as file:
writer = csv.writer(file)
# Write header

writer.writerow(["Time", "Left Hip Angle", "Right Hip Angle", "Left Knee Angle", "Right Knee Angle"])
# Write data rows

writer.writerows(data)

fig,ax = plt.subplots()
plt.title("Angles vs Time") plt.xlabel("Time (seconds)") plt.ylabel("Angle (degrees)") plt.plot(x_axis, hip_r,'r') plt.plot(x_axis, hip_l,'b') plt.plot(x_axis, knee_r,'g')
plt.plot(x_axis, knee_l,'y')

plt.legend(["Right Hip", "Left Hip", "Right Knee", "Left Knee"]) plt.show()

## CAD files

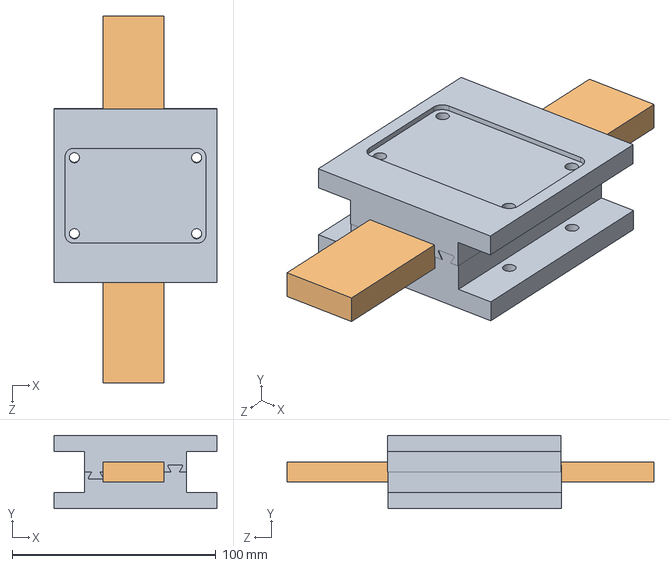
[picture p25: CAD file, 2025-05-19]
Design/dovetail_link.SLDASM
80.0 x 36.0 x 180.0 mm
link_sample
Dovetail x 2

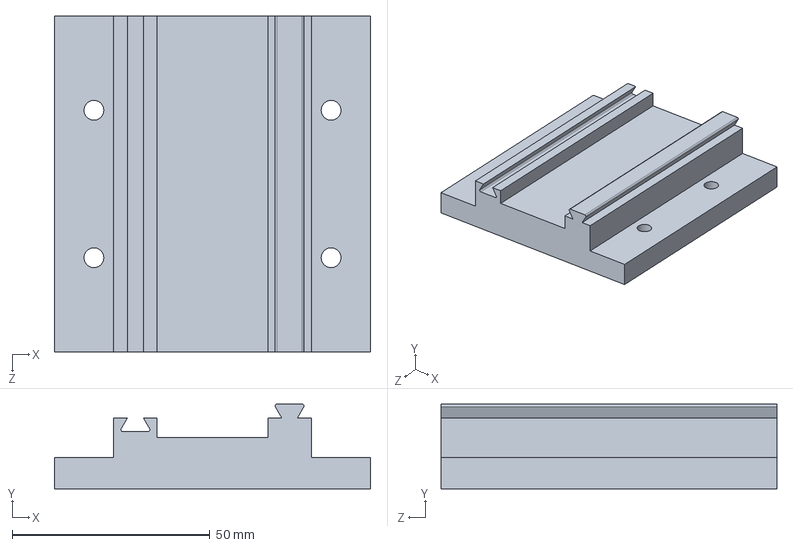
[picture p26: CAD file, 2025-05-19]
Design/Dovetail.SLDPRT
80.0 x 21.5 x 85.0 mm

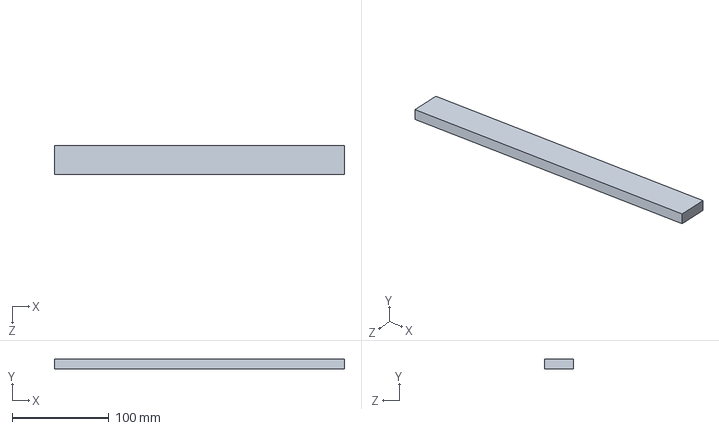
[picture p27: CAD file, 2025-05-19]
Design/link_thigh.SLDPRT
300.0 x 10.0 x 30.0 mm

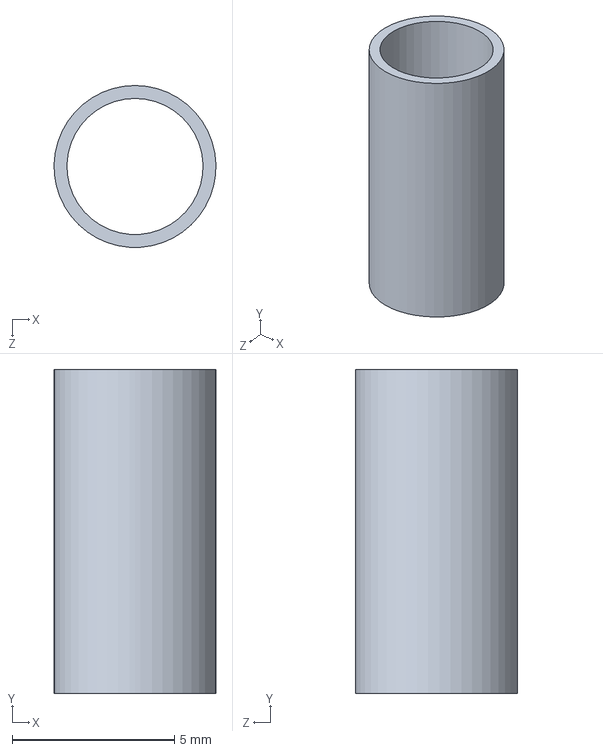
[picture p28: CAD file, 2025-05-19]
Design/spacer.SLDPRT
5.00 x 10.0 x 5.00 mm

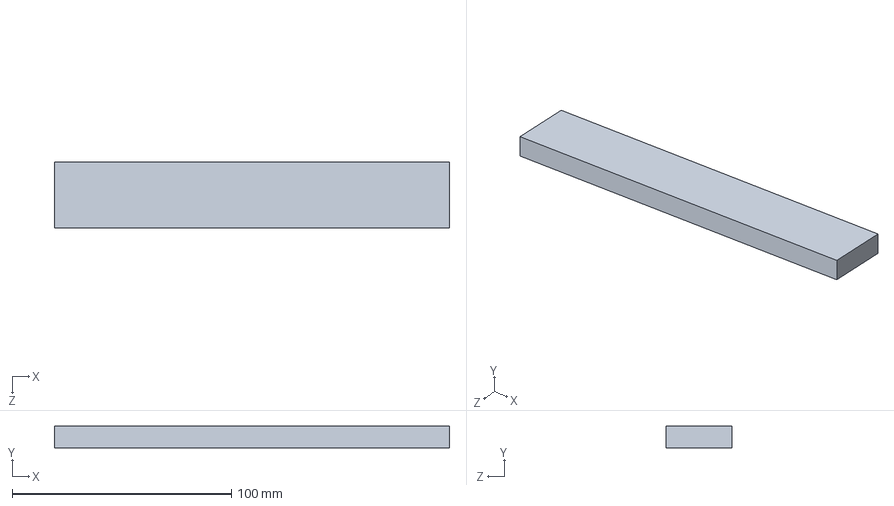
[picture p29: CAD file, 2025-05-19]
Design/link_sample.SLDPRT
180.0 x 10.0 x 30.0 mm

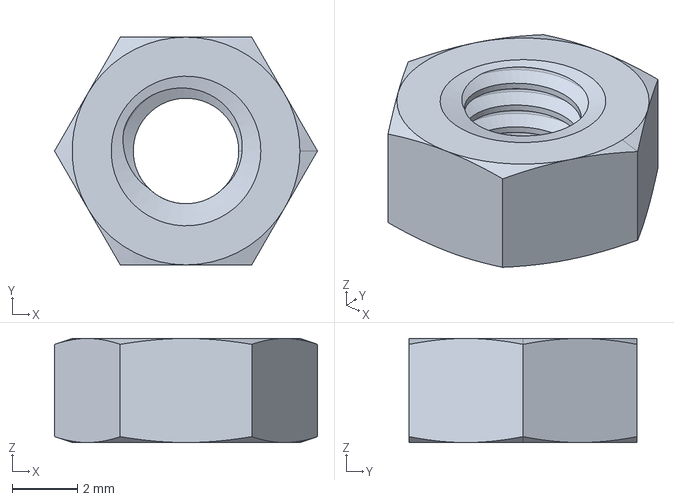
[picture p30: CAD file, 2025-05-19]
Design/bolt/nut_m4.stp
8.08 x 7.00 x 3.20 mm

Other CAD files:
Design/Dovetail_drawing.SLDDRW
Design/bolt/prt Files/M4x10.prt
Design/bolt/prt Files/M4x12.prt
Design/bolt/prt Files/M4x14.prt
Design/bolt/prt Files/M4x16.prt
Design/bolt/prt Files/M4x18.prt
Design/bolt/prt Files/M4x20.prt
Design/bolt/prt Files/M4x22.prt
Design/bolt/prt Files/M4x25.prt
Design/bolt/prt Files/M4x30.prt
Design/bolt/prt Files/M4x35.prt
Design/bolt/prt Files/M4x40.prt
Design/bolt/prt Files/M4x45.prt
Design/bolt/prt Files/M4x5.prt
Design/bolt/prt Files/M4x50.prt
Design/bolt/prt Files/M4x6.prt
Design/bolt/prt Files/M4x8.prt

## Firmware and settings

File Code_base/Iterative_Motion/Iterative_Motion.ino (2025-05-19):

#include <Wire.h>
#include <Adafruit_Sensor.h>
#include <Adafruit_BNO055.h>
#include <utility/imumaths.h>

#define SHIN_VOLTAGE 25
#define SHIN_CW 19
#define SHIN_CCW 23

#define THIGH_VOLTAGE 26
#define THIGH_CW 18
#define THIGH_CCW 4

unsigned long cycle_start = 0;
const unsigned long gait_time = 22000;

// Percentage of the gait cycle for various limb positions
const float toe_off_time_thigh = 0.25;
//const float full_contraction_thigh = 0.55;
const float mid_swing_thigh = 0.7;
const float full_extension_thigh = 0.75;

const float toe_off_time_shin = 0.245;
//const float full_contraction_shin = 0.43;
const float mid_swing_shin = 0.49;
const float full_extension_shin = 0.745;
const float neutral = 1;

// PWM channel parameters
const int freq = 5000;
const int shinChannel = 0;
const int thighChannel = 1;
const int debugChannel = 2;
const int resolution = 10;

bool safe = 1;

// Pre-defined way points
double thigh_points[4] = { 10, -8, -10, 0};
double shin_points[4] = { 165, 168, 175, 170};
int thigh_iteration = 0;
int shin_iteration = 0;

Adafruit_BNO055 bno_thigh = Adafruit_BNO055(55, 0x28, &Wire);
Adafruit_BNO055 bno_shin = Adafruit_BNO055(55, 0x29, &Wire);

double Kp_thigh = 2, thigh_controller_output, thigh_angle, thigh_error;
double Kp_shin = 2, shin_controller_output, shin_angle, shin_error;

void setup() {
  Serial.begin(115200);
  while (!Serial) delay(10);

  Serial.println("Setup initialized.");

  pinMode(SHIN_CW, OUTPUT);
  pinMode(SHIN_CCW, OUTPUT);

  pinMode(THIGH_CW, OUTPUT);
  pinMode(THIGH_CCW, OUTPUT);

  ledcSetup(thighChannel, freq, resolution);
  ledcSetup(shinChannel, freq, resolution);

  ledcAttachPin(THIGH_VOLTAGE, thighChannel);
  // ledcAttachPin(2, thighChannel);
  ledcAttachPin(SHIN_VOLTAGE, shinChannel);

  delay(10);

  Serial.println("Configured output and PWM pins.");

  if (!bno_thigh.begin()) {
    Serial.print("Problem with thigh BNO, rectify.");
    while (1)
      ;
  }

  if (!bno_shin.begin()) {
    Serial.print("Problem with shin BNO, rectify.");
    while (1)
      ;
  }

  delay(10);

  int setup_gap = 3;
  while (setup_gap > 0) {
    Serial.print("Setup complete. Executing loop in ");
    Serial.print(setup_gap);
    Serial.println(" seconds");
    delay(1000);
    setup_gap = setup_gap - 1;
  }

  Serial.println("Starting Gait.");

  unsigned long cycle_start = millis();
}

void loop() {

  controller();

  delay(20);
}


void update_values() {

  unsigned long current_time = millis();
  if (safe) {
    if (current_time - cycle_start < (long)(toe_off_time_thigh * gait_time)) {
      thigh_iteration = 0;
      if (current_time - cycle_start < (long)(toe_off_time_shin * gait_time)) {
        shin_iteration = 0;
      } else if (current_time - cycle_start < (long)(mid_swing_shin * gait_time)) {
        shin_iteration = 1;
      }
    } else if (current_time - cycle_start < (long)(mid_swing_thigh * gait_time)) {
      thigh_iteration = 1;
      if (current_time - cycle_start < (long)(mid_swing_shin * gait_time)) {
        shin_iteration = 1;
      } else if (current_time - cycle_start < (long)(full_extension_shin * gait_time)) {
        shin_iteration = 2;
      }
    } else if (current_time - cycle_start < (long)(full_extension_thigh * gait_time)) {
      thigh_iteration = 2;
      if (current_time - cycle_start < (long)(full_extension_shin * gait_time)) {
        shin_iteration = 2;
      } else if (current_time - cycle_start < (long)(neutral * gait_time)) {
        shin_iteration = 3;
      }
    } else if (current_time - cycle_start < (long)(neutral * gait_time)) {
      thigh_iteration = 3;
      shin_iteration = 3;
    } else if (current_time - cycle_start >= (long)(neutral * gait_time)) {
      cycle_start = current_time;
    }
  } else {
    thigh_iteration = 3;
    shin_iteration = 3;
  }
}

void feedback() {
  update_values();

  sensors_event_t theta_thigh, theta_shin;

  bno_thigh.getEvent(&theta_thigh, Adafruit_BNO055::VECTOR_GRAVITY);
  bno_shin.getEvent(&theta_shin, Adafruit_BNO055::VECTOR_GRAVITY);

  thigh_angle = get_angle(&theta_thigh);
  Serial.println("thigh_angle: ");
  Serial.println(thigh_angle);
  shin_angle = 180 + get_angle(&theta_thigh) - get_angle(&theta_shin);
  Serial.println("shin_angle: ");
  Serial.println(shin_angle);

  if (abs(thigh_angle) >= 30) {
    safe = 0;
  }
  if (!safe) {
    thigh_iteration = 3;
    shin_iteration = 3;
    if ((abs(thigh_error) <= 2) && (abs(shin_error) <= 2)) {
      Serial.println("Reached safe state, restarting gait cycle.");
      cycle_start = millis();
      safe = 1;
    }
  }

  thigh_error = thigh_points[thigh_iteration] - thigh_angle;
  shin_error = shin_points[shin_iteration] - shin_angle;
}

double get_angle(sensors_event_t* event) {
  double temp_angle, x, y, z;
  event->type == SENSOR_TYPE_GRAVITY;
  x = event->acceleration.x;
  y = event->acceleration.y;
  z = event->acceleration.z;
  if ((x < 0) && (y < 0)) {
    temp_angle = (atan(x / y) * 57.2957795131);
  } else if ((x > 0) && (y < 0)) {
    temp_angle = (atan(x / y) * 57.2957795131);
  } else if ((x > 0) && (y > 0)) {
    temp_angle = (atan(x / y) * 57.2957795131);
  } else {
    temp_angle = (atan(x / y) * 57.2957795131);
  }
  if (temp_angle > 180) {
    temp_angle = temp_angle - 270;
  }
  return temp_angle;
}


void controller() {
  feedback();

  if (thigh_error >= 0) {
    digitalWrite(THIGH_CW, HIGH);
    digitalWrite(THIGH_CCW, LOW);
  } else {
    digitalWrite(THIGH_CW, LOW);
    digitalWrite(THIGH_CCW, HIGH);
  }

  if (shin_error >= 0) {
    digitalWrite(SHIN_CW, LOW);
    digitalWrite(SHIN_CCW, HIGH);
  } else {
    digitalWrite(SHIN_CW, HIGH);
    digitalWrite(SHIN_CCW, LOW);
  }

  if (safe) {
    shin_controller_output = abs(Kp_shin * shin_error);
    thigh_controller_output = abs(Kp_thigh * thigh_error);
  }

  else {
    shin_controller_output = 10;
    thigh_controller_output = 10;
  }

  actuation();
}

void actuation() {
  int shin_duty, thigh_duty;
  if (abs(shin_error) > 3) {
    shin_duty = int(map(shin_controller_output, 0, 240, 102, 922));
  } else if (abs(shin_error) <= 3) {
    shin_duty = 102;
  }

  if (abs(thigh_error) > 3) {
    thigh_duty = int(map(thigh_controller_output, 0, 240, 102, 922));
  } else if (abs(thigh_error) <= 3) {
    thigh_duty = 102;
  }
  ledcWrite(shinChannel, shin_duty);
  ledcWrite(thighChannel, thigh_duty);
}

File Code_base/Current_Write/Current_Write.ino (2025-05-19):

// setting PWM properties
const int freq = 5000;
const int ledChannel = 0;
const int resolution = 10;

int number = 102;
String inString = "";

void setup() {
  Serial.begin(115200);
  while (!Serial) {
    delay(100);
  }

  pinMode(23, OUTPUT);
  pinMode(19, OUTPUT);
  digitalWrite(23, HIGH);
//  digitalWrite(19, HIGH);
  
  // configure LED PWM functionalitites
  ledcSetup(ledChannel, freq, resolution);
  
  // attach the channel to the GPIO to be controlled
  ledcAttachPin(25, ledChannel);
  ledcAttachPin(2, ledChannel);
}

void loop() {
  while (Serial.available() > 0) {
    int inChar = Serial.read();  
    
    if (isDigit(inChar)) {
      inString += (char)inChar;
    }
    
    if (inChar == '\n') {
      int temp = inString.toInt();
      
      if ((temp >= 102) && (temp <= 922)) {
        number = inString.toInt();
      }
      else if (temp > 922) {
        number = 922;
      }
      else if (temp < 102) {
        number = 102;
      }
      inString = "";
    }
  }
  Serial.println(number);
  ledcWrite(ledChannel, number);
  delay(100);
}
